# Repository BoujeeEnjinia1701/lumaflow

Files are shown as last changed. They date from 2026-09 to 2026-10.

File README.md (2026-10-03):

# LumaFlow

     

**Area:** Water Security · **TRL:** 3 of 9 (proof of concept on paper) · **Value-engineering target:** $340 USD · **Difficulty:** 2 of 5

Inline UV-C LED reactor with a flow-activated switch and a dose monitor, sized for a household tap.

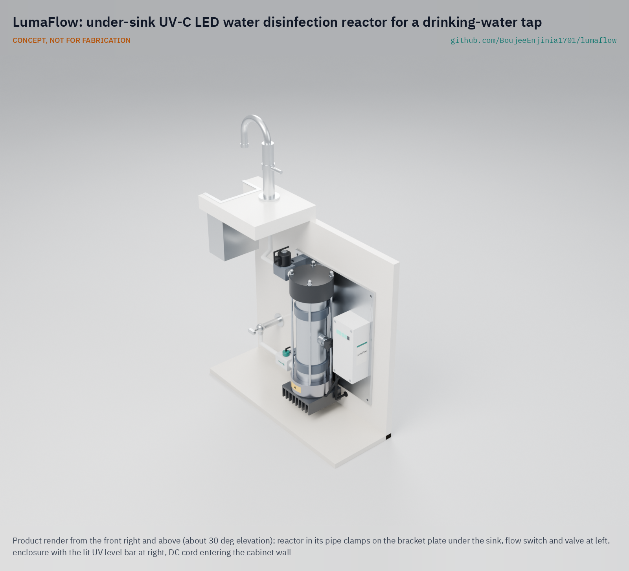
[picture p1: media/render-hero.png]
LumaFlow: under-sink UV-C LED water disinfection reactor for a drinking-water tap, product render


[Exploded render](media/render-exploded.png) · [Detail render](media/render-detail.png) · [Interactive 3D model](media/viewer.html) · [Concept blueprint (PDF)](media/concept-blueprint.pdf) · [General arrangement (PDF)](cad/drawings/LMF-DWG-001.pdf) · [Calculations](docs/04-calcs/01-sizing.md) · [Prototype build plan](docs/05-build-plan.md) · [Design decisions](docs/06-design-decisions.md) · [Review note](docs/REVIEW.md)

## Concept rationale

A UV-C LED reactor that runs only while water flows turns the LED's main weakness, low efficiency, into a small cost: at a household's few minutes of use a day, six LEDs use about 3.8 kWh a year, where a mercury lamp left on all day uses 114 to 193 kWh. Shining the LEDs along a wide, reflective tube, rather than wrapping lamps around a sleeve, keeps the part count low and puts every LED behind one flat quartz window that is easy to seal and service. A photodiode in the tube wall and a normally closed valve mean that a weak dose stops the water rather than passing it silently.

The design is open and garage-buildable because the people who most need point-of-use disinfection, households on private wells and small water projects, are the least served by closed commercial units. Every dimension, dose calculation and part is published, so a university lab, a maker space or a water charity can build one from catalog LEDs, a stainless tube, a machined end cap and push-fit plumbing, test it and improve it.

## Burning platform

Unsafe water remains one of the largest preventable causes of illness. In 2022, 2.2 billion people lacked safely managed drinking water, and at least 1.7 billion used a source contaminated with faeces; microbiologically contaminated drinking water is estimated to cause about 505,000 diarrhoeal deaths each year ([WHO drinking-water fact sheet](https://www.who.int/news-room/fact-sheets/detail/drinking-water)).

The gap is not confined to low-income countries. More than 43 million people in the United States, about 15 % of the population, rely on private domestic wells whose water quality is not regulated by the federal Safe Drinking Water Act ([USGS](https://www.usgs.gov/mission-areas/water-resources/science/domestic-private-supply-wells)), and an estimated three to four million Canadians are served by private supplies ([CMAJ, 2010](https://www.cmaj.ca/content/182/10/1061)). Each of those households is its own water utility, usually without monitoring.

## Where it could be used

### By industry

| Industry | Use |
| --- | --- |
| Residential water treatment | Point-of-use disinfection at a kitchen drinking-water tap on a private well or rainwater tank |
| Rural health clinics | A low-maintenance disinfection stage for the tap used for drinking and hand hygiene |
| Schools and community water points | A metered, monitored barrier on an indoor drinking tap, with a visible fault light |
| Humanitarian and development programs | An open reference design that local workshops can build and repair |
| Research and education | A test bed for reactor optics, LED aging and dose sensing |
| Recreational and off-grid buildings | Cabins, boats and camps on untreated supplies, with 24 V DC power |

### By country or region

| Country or region | Why it matters there |
| --- | --- |
| United States | More than 43 million people drink from private wells outside federal drinking-water regulation ([USGS](https://www.usgs.gov/mission-areas/water-resources/science/domestic-private-supply-wells)) |
| Canada | Three to four million people, about one in eight, are served by private supplies ([CMAJ](https://www.cmaj.ca/content/182/10/1061)) |
| Sub-Saharan Africa | The gap between urban and rural coverage of safely managed drinking water, 38 percentage points in 2022, is the widest of any region ([WHO and UNICEF JMP, 2023, p. 14](https://cdn.who.int/media/docs/default-source/wash-documents/jmp-2023_layout_v3launch_5july_low-reswhowebsite.pdf)); rural households and clinics are the users a small, flow-switched unit serves |
| Bangladesh | In the national Multiple Indicator Cluster Survey of 2019, children in households whose drinking water carried high *E. coli* contamination were 2.28 times as likely to have diarrhea as those in low-risk households ([Khan et al., 2022](https://link.springer.com/article/10.1007/s11356-021-18460-9)) |
| Latin America and the Caribbean | The gap between urban and rural coverage of safely managed drinking water, 27 percentage points in 2022, is second only to sub-Saharan Africa ([WHO and UNICEF JMP, 2023, p. 14](https://cdn.who.int/media/docs/default-source/wash-documents/jmp-2023_layout_v3launch_5july_low-reswhowebsite.pdf)) |
| Pacific islands (Oceania) | At least basic drinking water reached 93 % of urban but only 51 % of rural people in 2022 ([WHO and UNICEF JMP, 2023, p. 14](https://cdn.who.int/media/docs/default-source/wash-documents/jmp-2023_layout_v3launch_5july_low-reswhowebsite.pdf)); a unit that runs on 24 V DC suits off-grid homes |

## What sparked the idea

The idea traces back to one of the first patents on ultraviolet water sterilization, filed on 7 June 1910 by Victor Henri, André Helbronner and Max von Recklinghausen ([US 1,151,267](https://patents.google.com/patent/US1151267)). Their apparatus kept a quartz mercury-vapor lamp outside the water, ran the liquid past it and lined the channel with reflecting metal "so that the rays which pass through the liquid are caused to re-traverse the same." LumaFlow keeps that arrangement, a light source behind a quartz window and a reflective channel, and swaps the mercury lamp for UV-C LEDs that switch on only when water flows.

## Problem

Point-of-use disinfection often depends on mercury UV lamps that break.

## Concept

Water flows up a stainless tube lined with high-reflectance PTFE (50 mm bore, 242 mm water column) while six 275 nm UV-C LEDs at the bottom shine up through a quartz window. A flow sensor switches the LEDs on only while water runs, and a UV-C photodiode in the tube wall estimates the dose; if it falls too low, a normally closed valve shuts off the water and an alarm sounds. A five-segment bar on the enclosure shows the UV level relative to the alarm threshold. The TRL 3 calculations ([LMF-CAL-001](docs/04-calcs/01-sizing.md)) give a dose of 51 to 75 mJ/cm² at the 1.2 L/min (0.32 gpm) design flow in clear water (90 %/cm UV transmittance), above the 40 mJ/cm² target, and 17 to 21 mJ/cm² in the 70 %/cm test water, which stays below it. The unit draws 22.6 W while flowing and 0.21 W on standby. Value-engineering target: USD 340. Estimated cost of the constructable design: USD 416 (USD 76 over the target; see the [design decisions register](docs/06-design-decisions.md)).

Full design precis: [docs/02-concept.md](docs/02-concept.md)

## Key components

- Six 275 nm UV-C LEDs on a heat sink with a board temperature sensor, cooled through a 316 stainless lower end cap into the water
- 316 stainless reactor tube with a high-reflectance PTFE liner (50 mm bore) and top disc; acetal upper cap shielded from UV-C
- Fused quartz window (57 x 10 mm) between the LEDs and the water
- Hall-effect flow sensor (15 Hz per L/min) acting as the flow switch
- UV-C photodiode dose monitor in the tube wall at mid height
- Controller with constant-current LED driver, normally closed shutoff valve, external 24 V adapter
- At installation: a sediment pre-filter and a pressure-limiting valve at 4 bar (58 psi) or less

The priced bill of materials is in [bom/bom.csv](bom/bom.csv); the parametric model is `cad/src/model.py`, with STEP and STL exports in `cad/step/` and `cad/stl/`.

## Building the prototype

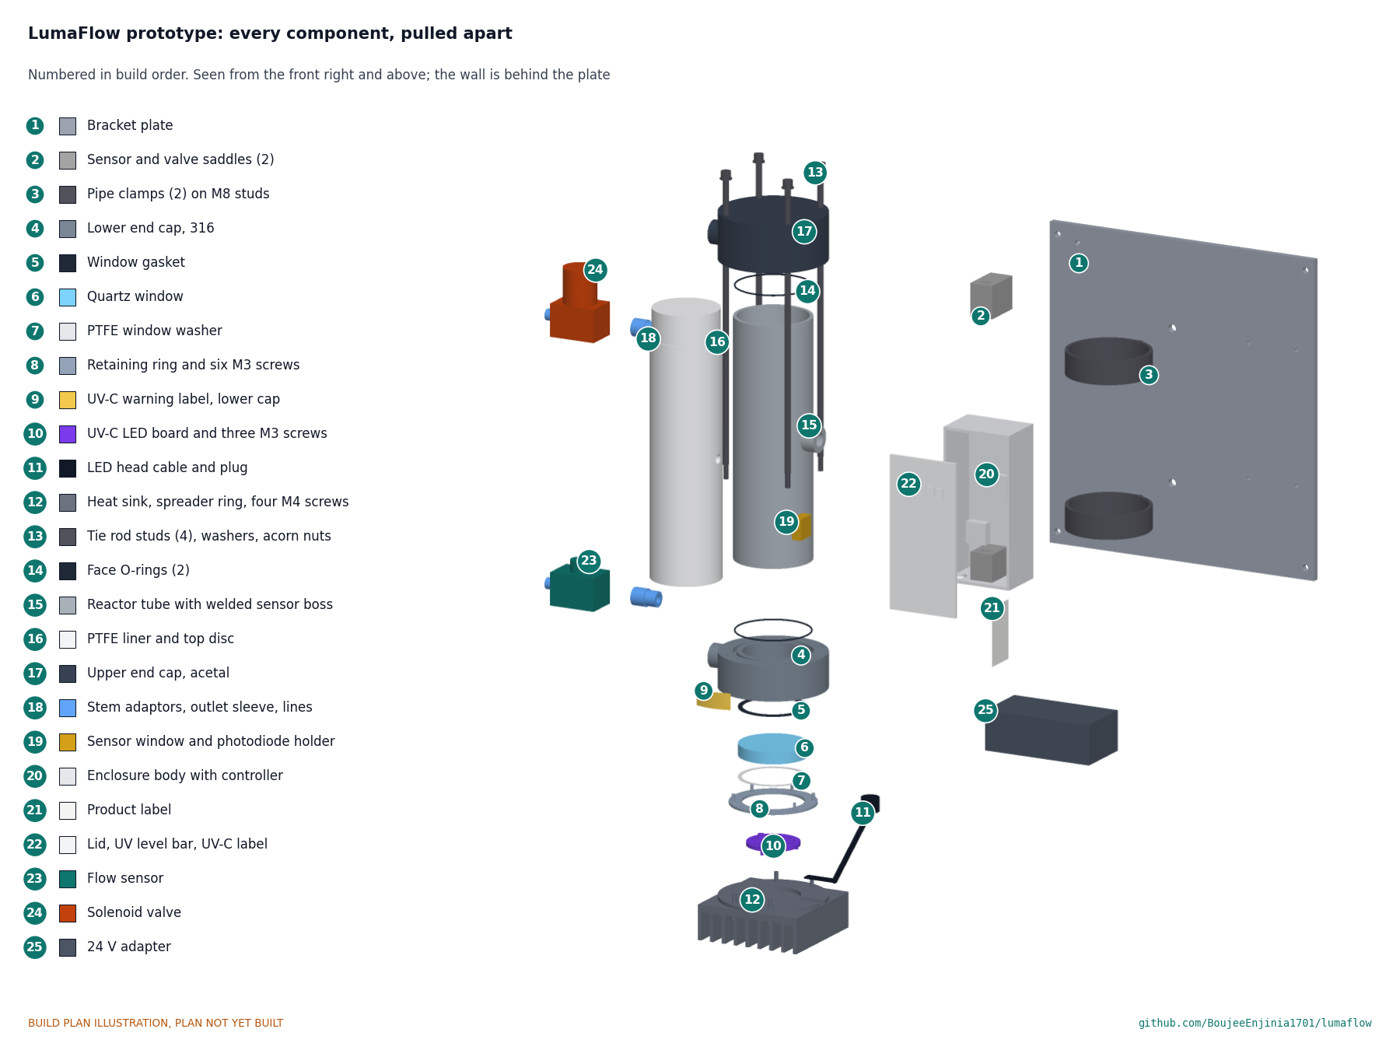
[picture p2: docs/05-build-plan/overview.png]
LumaFlow prototype: every component pulled apart and numbered in build order


The [prototype build plan](docs/05-build-plan.md) (LMF-BLD-001) shows, in pictures, how to make each of the 25 components and put them together in sixteen steps; nothing has been built yet. The made parts are a drilled aluminium bracket plate with printed saddles, a machined stainless lower end cap, a stainless window retaining ring, a drilled heat sink and spreader ring, tie rod studs, the stainless tube with a welded sensor boss, the PTFE liner, a machined acetal upper end cap, a photodiode holder and a printed enclosure; the rest is bought. Writing the plan made the design buildable: the window now goes in from below and is clamped on a PTFE washer by a ring, the tube ends seal on O-rings, the tie rods are studs in the lower cap, the upper cap's roof is thicker, the ports are threaded and the bracket holds the reactor in two pipe clamps (LMF-DDR-003, accepted by Amish on 2026-10-02). The LED head plugs in under the enclosure through an interlock loop on a cable too short for the head to come off while plugged in, and the lid carries a five-segment UV level bar. Every picture is drawn from the model, and the model checks that each part touches what it should and clears what it should not.

## Safety

> UV-C light damages eyes and skin. Interlock the housing and the LED head so LEDs cannot run when either is open, and keep the UV-C warning labels in place. LumaFlow is a research and educational prototype, not a certified water treatment device, and its dose is calculated, not measured; do not rely on it as a barrier for drinking water. See the safety section of the [design precis](docs/02-concept.md).

## Repository layout

| Folder | Contents |
| --- | --- |
| `docs/` | Problem, concept, requirements, calculations and design decisions |
| `cad/src/` | build123d Python source, the source of truth for all geometry |
| `cad/step/`, `cad/stl/` | Exported models for FreeCAD, other CAD tools and printing |
| `cad/drawings/` | 2D sketches and dimensioned drawings |
| `bom/` | Bill of materials |
| `electronics/` | KiCad schematics and PCB layouts |
| `firmware/` | Microcontroller code |
| `media/` | Renders, perspectives and photos |
| `build-log/` | Dated prototyping notes |

## Documentation

Controlled documents follow the portfolio [documentation standard](.kit/STANDARDS.md). Each carries a document ID (LMF-PRC-001 for the precis), a version and a revision history. Branded PDFs are built with `python .kit/render.py` and attached to GitHub Releases when a document is tagged, for example `LMF-PRC-001/v1.0`.

## Credits

Designed by Amish Chadha. See [CONTRIBUTORS.md](CONTRIBUTORS.md) for roles. To cite this design, use [CITATION.cff](CITATION.cff) (GitHub shows it as "Cite this repository").

AI assistance (Claude) was used to accelerate concept renders, prototype documentation and first-pass sizing calculations. Design direction and all decisions are Amish Chadha's, recorded in this repository's decision records (`docs/decisions/`).

## Licenses

- **Hardware** (CAD, drawings, BOM, electronics): [CERN-OHL-S v2](LICENSE)
- **Software** (firmware, scripts, notebooks): [MIT](LICENSE-SOFTWARE)

A project of the [Design Molecule](https://designmolecule.com) lab.

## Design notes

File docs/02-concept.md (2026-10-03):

---
doc_id: LMF-PRC-001
title: LumaFlow design precis
project: LumaFlow
doc_type: Design precis
version: "0.8"
status: Draft
date: '2026-10-02'
author: Amish Chadha
license: CERN-OHL-S-2.0
revisions:
- version: "0.1"
  date: '2026-09-24'
  author: Amish Chadha
  change: Initial scaffold
- version: "0.2"
  date: '2026-09-25'
  author: Amish Chadha
  change: Populate to TRL 2 (architecture, components, dose, power, thermal and window estimates, safety, media)
- version: "0.3"
  date: '2026-09-25'
  author: Amish Chadha
  change: Record Amish's decisions (LMF-DDR-001); TRL 3 design (316 lower cap, PTFE-shielded acetal upper cap, tie rods); numbers replaced by LMF-CAL-001, including the dose shortfall
- version: "0.4"
  date: '2026-09-25'
  author: Amish Chadha
  change: Recommendations accepted by Amish (DDR-002); 50 mm bore with high-reflectance PTFE liner at 1.2 L/min, wall dose sensor, 15 Hz per L/min flow sensor, pressure limiter, thermal cut-back; numbers from LMF-CAL-001 v0.2
- version: "0.5"
  date: '2026-09-26'
  author: Amish Chadha
  change: Budget top-up approved by Amish ($340); R16 met
- version: "0.6"
  date: '2026-10-01'
  author: Amish Chadha
  change: "Design made constructable (LMF-DDR-003): components 13 to 18 updated; cost reported against the value-engineering target"
- version: "0.7"
  date: '2026-10-02'
  author: Amish Chadha
  change: "UV level bar, labels, idle pulse and partner as decided on 2026-10-02 (LMF-DEC-001)"
- version: "0.8"
  date: '2026-10-02'
  author: Amish Chadha
  change: "Approved follow-ups carried out (LMF-CAL-001 v0.6): window on a 0.5 mm PTFE washer, LED head interlock plug, UV level bar in place of the status light, labels; figures updated"
---

# LumaFlow design precis

## Summary

LumaFlow is an inline UV-C LED reactor with a flow-activated switch and a dose monitor, sized for a household tap. Water flows up a stainless tube lined with high-reflectance PTFE, with a 50 mm bore, while six 275 nm LEDs at the bottom shine up a 242 mm water column through a quartz window. A Hall-effect flow sensor turns the LEDs on only while water runs, and a UV-C photodiode in the tube wall at mid height measures the light in the water, which lets the controller estimate the dose and close a valve if it falls too low.

The first TRL 3 calculation (LMF-CAL-001 v0.1) showed that the original 25 mm bore lost half of the light to the wall and delivered only 14.7 to 19.0 mJ/cm² at 2 L/min. Amish accepted the recommended route on 2026-09-25 (LMF-DDR-002): a wider bore, a higher-reflectance liner and a modest flow cut. With a 50 mm bore, a liner reflectance of 0.95 and a design flow of 1.2 L/min (0.32 gpm), the reduction equivalent dose (RED) in clear water (90 %/cm UV transmittance) is 50.9 to 74.9 mJ/cm², so **R2 is met**. At the 70 %/cm test condition it is 17.0 to 21.3 mJ/cm² (**R3 not met**, accepted by decision D1). The unit draws 22.6 W while water flows and 0.21 W on standby. Value-engineering target: USD 340. Estimated cost of the constructable design: USD 416 (USD 76 over the target). The design was made physically buildable on 2026-10-01 (LMF-DDR-003, accepted by Amish on 2026-10-02 with the window seat changed to a PTFE washer), and the prototype build plan LMF-BLD-001 shows how to make and fit every part.

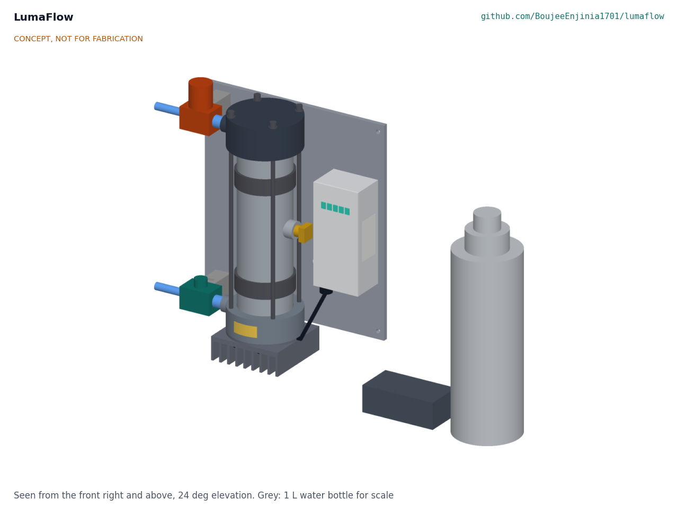
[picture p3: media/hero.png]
Hero render


*Figure 1. LumaFlow model, mounted on its wall bracket under a sink, with the 24 V adapter on the cabinet floor. The grey 1 L bottle is for scale.*

## How it works

1. **Flow starts.** When someone opens the drinking-water faucet, water enters through the Hall-effect flow sensor (item 8). Its pulses, 15 per second for each L/min, tell the controller that flow has started and how fast it is.
2. **LEDs on.** The controller opens the normally closed outlet valve (item 11) and drives the six 275 nm LEDs (item 4) at 350 mA. At the 0.3 L/min threshold the first sensor pulse arrives within 0.22 s, so switch-on takes up to 0.24 s against the 0.5 s target (LMF-CAL-001, D2). LEDs reach full output almost at once, so no warm-up or bypass is needed.
3. **Irradiate.** The LEDs sit 1.3 mm under a 10 mm fused quartz window (item 3), which rests on a 0.5 mm PTFE washer on its stainless retaining ring, in the 316 stainless lower end cap (item 6). Water enters the lower cap just above the window, flows up the 50 mm bore of the PTFE liner (item 2) at about 1 cm/s and leaves through a 316 insert in the acetal upper cap (item 7) after about 22 s. The wide bore lets light cross more water between wall reflections, and the liner returns about 95 % of the light that reaches it, so the water absorbs 53 % of the LED output at 90 %/cm.
4. **Measure.** A UV-C photodiode (item 9) behind an 8 mm quartz window in the tube wall at mid height sees the light in the water. Its signal falls if the water's UVT drops, the liner or window fouls or the LEDs age. The controller combines that reading with the flow rate to estimate the dose, using a proportional rule that blames every loss of signal on the LEDs, which always under-reads (LMF-CAL-001, C3 to C5).
5. **Alarm and shut off.** If the estimated dose falls below 40 mJ/cm², the flow exceeds its limit, a sensor fails or the enclosure lid is opened, the controller closes the valve, sounds the buzzer and shows the fault on the UV level bar. In normal running the five-segment bar shows the UV level relative to the alarm threshold, read from the wall sensor (R18); it is not a dose reading. With fresh LEDs this happens below about 89 %/cm UVT. The valve also closes if power is lost, so no untreated water passes silently.
6. **Stay cool.** A temperature sensor on the LED board lets the controller cut LED current above 50 °C. A cut-back lowers the dose, which the photodiode sees, so the alarm rule still protects the user.
7. **Flow stops.** The LEDs stay on for 5 s after flow stops, then everything switches off.

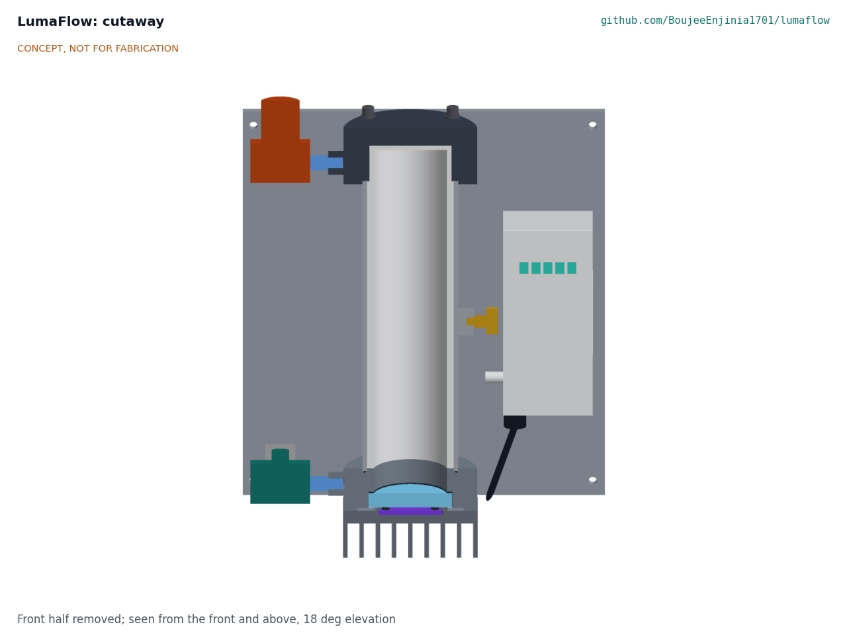
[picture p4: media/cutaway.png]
Cutaway


*Figure 2. Cutaway through the reactor axis, looking at the wall. From the bottom: heat sink, LED board, quartz window in the stainless lower cap with the inlet, the 50 mm PTFE-lined tube with the wall photodiode on the right, and the PTFE top disc in the acetal upper cap with the outlet insert. The controller board is in the enclosure on the right.*

## Main components

Numbers match the exploded view (Figure 3), `bom/bom.csv` and drawing LMF-DWG-001 Rev P4.

Table 1. Main components.

| # | Component | Choice | Notes |
| --- | --- | --- | --- |
| 1 | Reactor tube | 316 stainless, 65 mm OD x 3 mm wall x 200 mm, one hole for the sensor window | Carries pressure and blocks all UV-C |
| 2 | High-reflectance PTFE liner and top disc | Sintered or expanded PTFE tube, 50 mm bore, 224 mm long, and a solid 3 mm top disc | Water channel and diffuse reflector (0.95 assumed); shields the acetal cap |
| 3 | Quartz window | UV-grade fused silica, 57 mm diameter x 10 mm, on a 51 mm seat | 6.18 MPa at 8 bar (LMF-CAL-001, G4) |
| 4 | UV-C LED array | Six 275 nm LEDs on a 32 mm circle, about 60 mW each at 350 mA, on one 44 mm aluminum-core board with an NTC temperature sensor | Decision D4; NTC for the thermal cut-back |
| 5 | Heat sink and spreader ring | Finned aluminum sink 90 x 90 x 30 mm and a 90 mm spreader ring to the stainless cap | Water carries 9.0 of 12.7 W of heat |
| 6 | Lower end cap | 316 stainless, 90 mm diameter x 30 mm, LED aperture, window seat, 3/8 in inlet | Stainless because its bore sees full UV-C and it is the water-cooled heat path (confirmed, LMF-DDR-002) |
| 7 | Upper end cap | Acetal, 90 mm diameter x 30 mm, liner pocket, outlet boss | Sees no UV-C behind the PTFE and the 316 insert |
| 8 | Hall-effect flow sensor | Food-grade, 0.3 to 6 L/min, 15 Hz per L/min or more | Switch and meter (decision D5) |
| 9 | UV-C wall photodiode and amplifier | SiC photodiode with transimpedance amplifier behind an 8 mm quartz window in the tube wall, on a clamp-on saddle | Dose monitor at mid height (LMF-DDR-002) |
| 10 | Controller and LED driver | Microcontroller, 350 mA constant-current driver with dimming, valve driver, NTC input, input fuse | Module-based; no custom PCB |
| 11 | Solenoid shutoff valve | 24 V DC, normally closed, food-grade | Closes on alarm or power loss (decision D6) |
| 12 | 24 V power adapter | Certified external adapter, 30 W | The only part at mains voltage (decision D8) |
| 13 | Electronics enclosure | Printed PETG body and lid, lid interlock, five-segment UV level bar on the lid (R18), buzzer, socket for the LED head plug, back screwed to the bracket plate | Dry side only. The LED head plug carries an interlock loop (R12); UV-C warning labels sit inside the lid and on the lower cap, and the product label on the enclosure side (item 19) |
| 14 | Wall bracket | 6 mm aluminium plate with two printed saddles for the flow sensor and valve | Holds the reactor vertical (decision D7) |
| 15 | Fittings, stem adaptors and outlet sleeve | 3/8 in push-fit, stainless stem adaptors in 1/4 BSPP ports, tee to the cold line, 1.2 L/min restrictor, 316 outlet sleeve | Restrictor enforces R1 |
| 16 | Tie rods and hardware | Four M5 316 studs on an 80 mm circle, threaded into the lower cap | 664 N each at 8 bar (G7) |
| 17 | Window retaining ring and seals | 316 ring under the window, EPDM window gasket, two EPDM face O-rings at the tube ends | Added by LMF-DDR-003 |
| 18 | Pipe clamps | Two rubber-lined 65 mm clamps on M8 studs | Added by LMF-DDR-003 |

Not in the BOM, but required at installation: a 5 µm sediment pre-filter and a pressure-limiting valve set at 4 bar (58 psi) or less (R17).

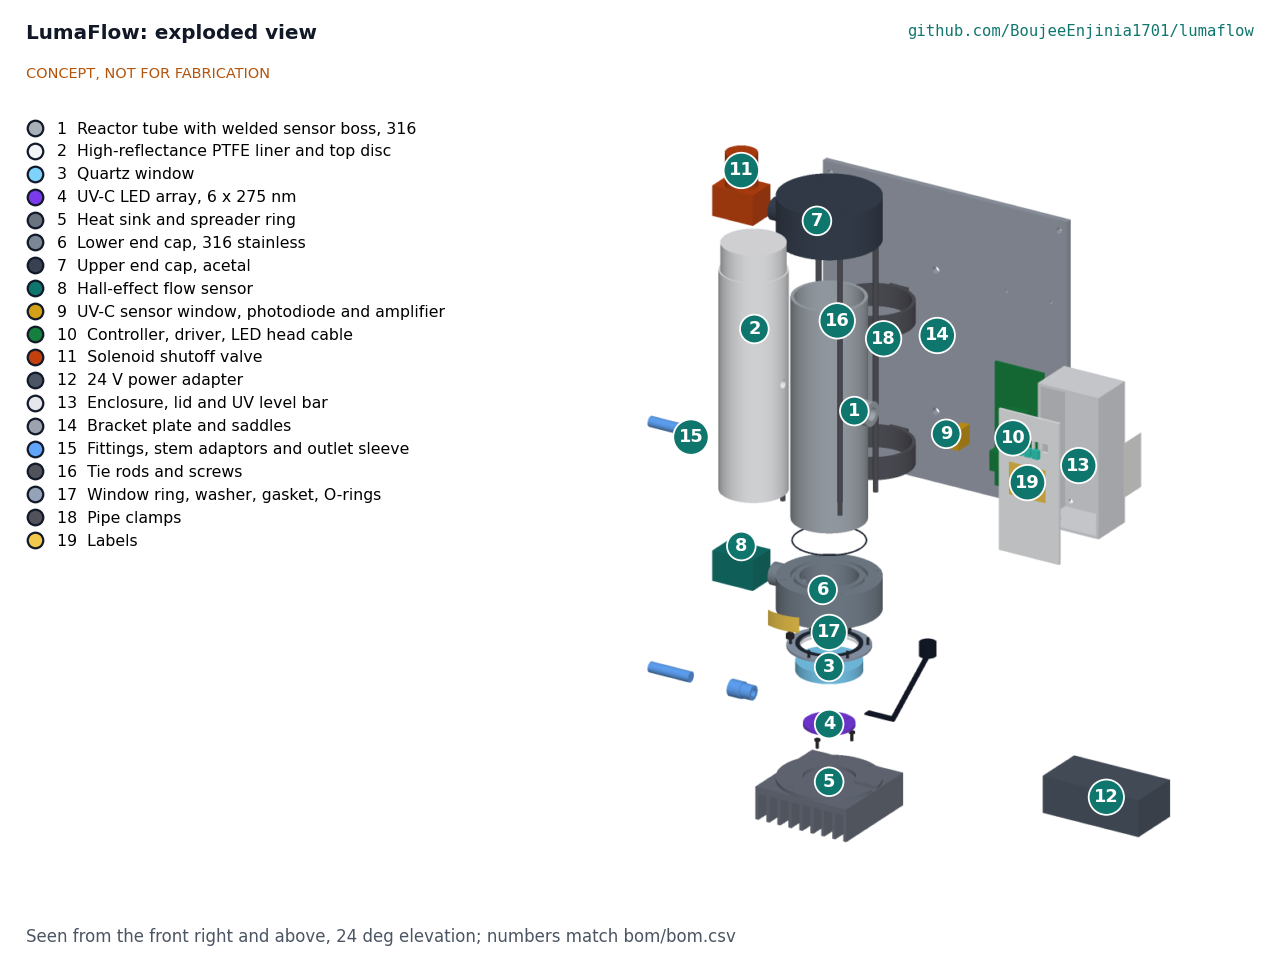
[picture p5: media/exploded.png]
Exploded view


*Figure 3. Exploded view with numbered callouts matching the BOM.*

## Key numbers

Every number in this section comes from LMF-CAL-001 v0.6, which states the assumptions; the tag in brackets is the line of `docs/04-calcs/sizing.py` that prints it.

### Flow

The channel is 50 mm across and 242 mm long and holds 474 mL [A1, A2]. At 1.2 L/min the mean velocity is 1.02 cm/s, the residence time between the ports 22.2 s and the Reynolds number 507, so the flow is laminar [A3, A4]. The entrance length is far longer than the tube [A5], so the true profile lies between plug flow and a parabola; the dose is given for both.

### UV-C dose

Table 2. Dose at 1.2 L/min [B3 to B6].

| Quantity | 90 %/cm UVT (design water) | 70 %/cm UVT (NSF/ANSI 55 test water) |
| --- | --- | --- |
| UV-C entering the water | 84.8 % of 0.36 W | 84.8 % of 0.36 W |
| UV-C absorbed by the water | 52.9 % | 66.5 % |
| Lost at the walls | 25.9 % | 16.4 % |
| Average dose | 75.4 mJ/cm² | 21.5 mJ/cm² |
| **RED (laminar to plug flow)** | **50.9 to 74.9 mJ/cm²** | **17.0 to 21.3 mJ/cm²** |
| Requirement | **R2 met** | **R3 not met** (accepted by D1) |

The liner reflectance is the main optical uncertainty: plain PTFE (0.80) would give 45.2 mJ/cm² and 0.90 gives 48.7 [B8]. LEDs 20 % below rating give 40.7 mJ/cm² [B9]. Six LEDs in this reactor reach 40 mJ/cm² up to 1.56 L/min, and 40 mJ/cm² with a 20 % margin up to 1.26 L/min [J1].

The dose target is the NSF/ANSI 55 Class A dose level for context only ([Fresh Water Systems](https://www.freshwatersystems.com/blogs/blog/nsf-class-a-and-class-b)). 40 mJ/cm² inactivates common bacteria and *Cryptosporidium* by several logs, but adenovirus needs about 186 mJ/cm² for 4 logs ([EPA UV toolkit](https://www.epa.gov/system/files/documents/2022-05/uv-toolkit-815-B-21-007_0.pdf)), so LumaFlow would not be a full virus barrier even at its target. Published flow-through LED reactors show that the reactor layout changes the delivered dose a great deal ([flow-through reactor efficiency](https://www.sciencedirect.com/science/article/abs/pii/S2214714420306966); [cylindrical reactor optimization](https://www.sciencedirect.com/science/article/abs/pii/S2213343724004962)).

### Dose monitor

The wall photodiode gives about 13.4 nA at 90 %/cm, 2.4 nA at 80 %/cm and 0.19 nA at 70 %/cm [C1], and its signal falls 2.6 times as fast as the dose [C2]. With the proportional mapping the alarm threshold is S/S_ref = 0.79 [C3]: it trips below about 89 %/cm with fresh LEDs, or when the LEDs have aged to 79 % of output in 90 %/cm water [C4]. R4 is at risk until the mapping and the 1 s fail-safe are shown in firmware and test. The five-segment UV level bar shows three segments in 90 %/cm water with fresh LEDs and loses its last segment where the alarm trips, so R18 is met [C6].

### Power and energy

Table 3. Power and energy [E1 to E6].

| Quantity | Value | Requirement |
| --- | --- | --- |
| LED electrical power | 13.02 W | |
| Power from mains while flowing | 22.6 W | R9 met (25 W) |
| Standby power | 0.21 W | R9 met (0.5 W) |
| LED on-time | 14.2 min/day, 86 h/year flowing; 92 h/year with the idle pulse of about 10 s every 4 h | 10,000 h in 108 years |
| Energy | 10.4 Wh/day flowing, 0.28 Wh/day for the idle pulse; 3.9 kWh/year | |
| Tap-scale mercury unit of 13 to 22 W running all day ([VIQUA spec sheet](https://viqua.com/wp-content/uploads/LIT520326_SpecSheet.pdf)) | 114 to 193 kWh/year | For comparison |

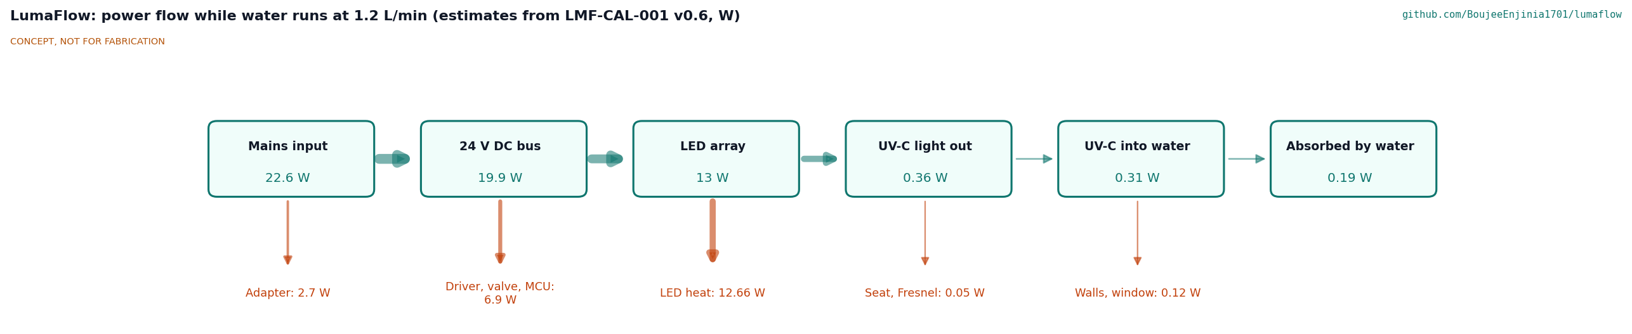
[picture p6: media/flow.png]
Power flow


*Figure 4. Power flow while water runs at 1.2 L/min. All values are estimates from LMF-CAL-001, in watts.*

### Heat

The LEDs turn 12.66 W into heat. The spreader ring passes it into the stainless lower cap, whose wetted bore gives it to the water (8.9 W; the water warms by 0.11 K), and the finned sink gives the rest to the air [F1, F2]. With continuous flow the LED board settles at 37.3 to 45.1 °C over the range of water-film coefficients, 40.5 °C nominal, so R10 is met [F3]. The board sensor cuts LED current above 50 °C as a backstop. With the LEDs stuck on and no flow the board heads for 53 °C [F6], where the cut-back acts; the controller must also switch the LEDs off when flow stops. A 10 s idle pulse warms the still head by 0.16 K [F7].

### Pressure and structure

The unit drops 0.15 bar at 1.2 L/min, not counting the restrictor, against 0.5 bar (R8 met, on assumed flow coefficients) [G2]. The 10 mm window carries 6.18 MPa at 8 bar against a design stress of 6.8 MPa (1,000 psi) for fused quartz ([Momentive](https://www.momentivetech.com/materials/fused-quartz-materials/quartz-properties/mechanical-properties)); R7 is met [G4]. An unprotected 16 bar spike would give 12.4 MPa, so the installation needs a pressure-limiting valve at 4 bar or less (R17), which keeps a transient of twice the setting at 6.18 MPa [G5]. Four M5 rods carry the 2,655 N end load [G7]. The window sits on a 0.5 mm PTFE washer whose 51 mm bore matches the retaining ring, so the open span and the stress are unchanged.

### Size and cost

The unit is 277 x 100 x 322 mm without the adapter, inside R14 [H1], and weighs about 5.0 kg dry and 5.4 kg full of water [H2]. Value-engineering target: USD 340. Estimated cost of the constructable design: USD 416 (USD 76 over the target) [I1]; the LEDs ($54), the stainless lower cap ($48) and the high-reflectance liner ($45) are the largest lines.

## Key design choices

Items marked "Decided" were decided by Amish on 2026-09-25, going with the recommendation (LMF-DDR-001, D1 to D9, and LMF-DDR-002, E1 to E8).

- **Axial LED head with a flat window (Decided, D3).** LEDs at one end shine along the tube through a flat window; this uses few LEDs and a simple reflector.
- **Wide bore, high-reflectance liner and 1.2 L/min (Decided, LMF-DDR-002).** A 50 mm bore with a liner of reflectance 0.95 and a modest flow cut close the dose gap found in LMF-CAL-001 v0.1. Lowering the flow alone (to about 0.6 L/min in the old reactor) is the fallback.
- **Wall dose sensor (Decided, LMF-DDR-002).** The photodiode moved from the top disc to the tube wall at mid height, with the proportional mapping kept. A second reference sensor near the LEDs, to separate LED aging from water quality, remains an optional idea.
- **275 nm LEDs (Decided, D4).** 275 nm gives the most UV-C output per dollar ([Tech-LED](https://tech-led.com/uv-c-leds-for-disinfection-and-sterilization-component-selection-265-280-nm/)); prices to be revisited. The dose calculation takes the organism's response at 275 nm as equal to that at 254 nm, which must be checked.
- **Design water quality and dose target (Decided, D1).** Design for 90 %/cm UVT, alarm and close the valve below 40 mJ/cm², and keep R3 visibly not met; flow limiting in poor water (Option C) is a later upgrade.
- **Flow sensor as the switch (Decided, D5), at 15 Hz per L/min or more (Decided, LMF-DDR-002).**
- **Normally closed outlet valve (Decided, D6).** Fails closed on alarm and on power loss.
- **Vertical mounting, flow upward (Decided, D7).** Purges air bubbles from under the window.
- **External 24 V adapter (Decided, D8).** Certified adapter on a GFCI or RCD-protected outlet.
- **End caps (Decided, LMF-DDR-002).** 316 stainless lower cap for UV-C exposure and heat, acetal upper cap shielded by the PTFE liner, top disc and a 316 outlet insert.
- **Pressure limiter and thermal cut-back (Decided, LMF-DDR-002).** A pressure-limiting valve upstream is an installation requirement (R17); a board temperature sensor cuts LED current above 50 °C (R10).
- **Budget (Decided, D2, and LMF-DDR-002).** `budget_usd` was $225. The recommendation to hold the budget until the dose route was chosen and then re-price has been carried out: the re-priced BOM is $338.00. Budget top-up to $340: decided by Amish, 2026-09-26 (LMF-DDR-002, O4); `budget_usd` is now $340.

## Safety

> **Safety:** LumaFlow emits UV-C light that injures eyes and skin, sits under pressure next to mains power in a wet cabinet, and is meant to make water safe to drink. Its dose is calculated, not measured. It is a research and educational prototype, not a certified water treatment device. Do not rely on it as a barrier for drinking water.

- **UV-C exposure.** UV-C burns the cornea and skin within seconds to minutes at close range and is invisible. The stainless tube, stainless lower cap, sealed sensor boss and PTFE-shielded upper cap block all UV-C in normal use. An interlock on the enclosure lid (a reed switch) and on the LED head (a loop in the head's plug, on a cable too short for the head to come off while plugged in) cuts LED power when either is opened, and no one should look into the bore, window or sensor port while the LEDs can run. Any bench work needs UV-C blocking eyewear and covered skin.
- **False sense of safety.** The calculated dose of 50.9 to 74.9 mJ/cm² at 90 %/cm rests on an assumed liner reflectance and organism response and has not been measured. In poorer water the dose falls quickly (17.0 mJ/cm² at 70 %/cm). UV does not remove chemicals, lead, nitrate or particles, leaves no residual disinfectant, and works poorly in cloudy or iron-rich water. A dose below target must stop the water, not only warn. Downstream pipework and the faucet can grow biofilm.
- **Pressure and leaks.** Supply pressure acts on the window, caps, sensor window and tubing; the larger window has a 9 % margin at 8 bar, and an unprotected spike would overstress it. Fit a shutoff valve and a pressure-limiting valve at 4 bar or less upstream. A cracked window would flood the LED head; the board runs at 24 V, so the hazard is short circuit and loss of treatment rather than shock. The fuse on the 24 V input and a leak check in the fault logic are required.
- **Electrical.** Mains is confined to the certified adapter, which should plug into a GFCI or RCD-protected outlet above any likely water level in the cabinet.
- **Heat.** The board temperature sensor cuts LED current above 50 °C, and the controller must switch the LEDs off when flow stops.
- **Materials.** UV-C degrades most plastics; only PTFE, quartz and metal may see it. Every wetted part must be food-contact grade.

## Open questions

- [x] Design water quality and dose target (decided, D1).
- [x] Estimate the reactor efficiency for this axial, laminar geometry (LMF-CAL-001: 0.67 laminar in the 50 mm bore).
- [x] Choose a route to close R2 (decided, LMF-DDR-002: 50 mm bore, 0.95 liner, 1.2 L/min).
- [x] Move the dose sensor to the tube wall (decided, LMF-DDR-002).
- [x] Confirm the end cap materials (decided, LMF-DDR-002).
- [x] Set the budget figure for the $338.00 BOM: $340, decided by Amish, 2026-09-26.
- [ ] Measure the wetted reflectance of the liner at 275 nm, and the organism response at 275 nm (TRL 4, on hold).
- [ ] Confirm the flow coefficients of the sensor and valve (R8) and the water-film coefficient in the lower cap (R10).
- [x] Idle LED pulse: a firmware rule runs the LEDs for about 10 s every 4 h of idle, with both interlocks and the valve logic unchanged; plate counts at TRL 4 check its effect. Decided by Amish, 2026-10-02 (LMF-DEC-001).
- [ ] Partner with real well-water UVT data: a university extension programme for private well owners, with the Texas A&M AgriLife Extension Texas Well Owner Network as the first candidate to approach. Decided by Amish, 2026-10-02 (LMF-DEC-001).

Concept media: [blueprint sheet](../media/concept-blueprint.pdf), [interactive 3D model](../media/viewer.html). General arrangement: [LMF-DWG-001](../cad/drawings/LMF-DWG-001.pdf).

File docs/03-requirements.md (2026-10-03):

---
doc_id: LMF-REQ-001
title: LumaFlow requirements
project: LumaFlow
doc_type: Requirements
version: "0.8"
status: Draft
date: '2026-10-02'
author: Amish Chadha
license: CERN-OHL-S-2.0
revisions:
- version: "0.1"
  date: '2026-09-24'
  author: Amish Chadha
  change: Initial scaffold
- version: "0.2"
  date: '2026-09-25'
  author: Amish Chadha
  change: First measurable requirements for TRL 2, with status against the concept estimates
- version: "0.3"
  date: '2026-09-25'
  author: Amish Chadha
  change: Record Amish's decisions (LMF-DDR-001); R16 redefined to $225; R7 design stress sourced (6.8 MPa); status from LMF-CAL-001
- version: "0.4"
  date: '2026-09-25'
  author: Amish Chadha
  change: Recommendations accepted by Amish (DDR-002); R1 to 1.2 L/min, R8 restated, R10 adds the thermal cut-back, new R17 pressure limiter; status from LMF-CAL-001 v0.2
- version: "0.5"
  date: '2026-09-26'
  author: Amish Chadha
  change: Budget top-up approved by Amish; R16 target $340, now met (LMF-CAL-001 v0.3)
- version: "0.6"
  date: '2026-10-01'
  author: Amish Chadha
  change: Rerun for the constructable design (LMF-DDR-003); R16 reported against the value-engineering target; R15 note
- version: "0.7"
  date: '2026-10-02'
  author: Amish Chadha
  change: "R12 status names the LED head loop wire; R18 added for the five-segment UV level bar (LMF-DEC-001, 2026-10-02)"
- version: "0.8"
  date: '2026-10-02'
  author: Amish Chadha
  change: "Approved follow-ups carried out (LMF-CAL-001 v0.6): R18 now met; R12 interlock now in the model and build plan; R2, R3, R4, R10 and R16 figures updated for the PTFE window washer and the new BOM lines"
---

# LumaFlow requirements

These are the requirements for the concept, checked by calculation at TRL 3 in LMF-CAL-001 v0.6, for the constructable design of LMF-DDR-003 with the decisions of 2026-10-02 (LMF-DEC-001) carried into it. The status column reports that note; bracketed tags such as [B5] point to the line of `docs/04-calcs/sizing.py` that carries the number. One requirement is **not met**: R3 (dose at the 70 %/cm test condition, accepted as not met by decision D1). R16 (cost) is reported against its value-engineering target: the constructable design is estimated at USD 416, USD 76 over the USD 340 target. One is at risk: R4. The dose targets (R2, R3) and the budget (R16) follow Amish's decisions in LMF-DDR-001; R1, R8, R10 and the new R17 follow the recommendations Amish accepted on 2026-09-25 (LMF-DDR-002).

Table 1. Requirements and status at TRL 3.

| ID | Requirement | Target | Status (LMF-CAL-001 v0.6) | Verification |
| --- | --- | --- | --- | --- |
| R1 | Deliver a useful drinking-water flow | 1.2 L/min (0.32 gpm) at the faucet, capped by a flow restrictor (was 2.0 L/min; reduced by LMF-DDR-002 so that R2 is met with margin) | Met by design [A3] | Restrictor rating; flow calculation |
| R2 | Deliver the Class A dose level in clear water | Reduction equivalent dose (RED) of 40 mJ/cm² or more at 1.2 L/min and UV transmittance (UVT) of 90 %/cm | Met (50.9 laminar to 74.9 plug mJ/cm², with the window on its 0.5 mm PTFE washer) [B5] | Ray-trace dose calculation; later biodosimetry |
| R3 | Deliver the Class A dose level at the NSF/ANSI 55 test water quality | RED of 40 mJ/cm² or more at 1.2 L/min and 70 %/cm UVT | **Not met** (17.0 to 21.3 mJ/cm²) [B6]; kept visibly not met by decision D1 | Dose calculation |
| R4 | Monitor the dose and fail safe | UV-C sensor in the tube wall reading through the water; visual and audible alarm and outlet valve closed within 1 s when the estimated dose falls below 40 mJ/cm², the sensor fails or power is lost | At risk: the wall signal is 13.4 nA at 90 %/cm and 0.19 nA at 70 %/cm, and the proportional mapping trips below about 89 %/cm, but the mapping and 1 s fail-safe need firmware and a test [C1, C4] | Signal calculation; later firmware and test |
| R5 | Switch with the flow | LEDs on within 0.5 s of flow above 0.3 L/min; LEDs held on for 5 s after flow stops; LEDs off otherwise | Met (0.24 s worst case with a 15 Hz per L/min sensor) [D2] | Timing calculation; later firmware sketch review |
| R6 | No mercury and no warm-up | No mercury in any part; full UV output within 0.1 s of switch-on | Met by design | Design review; LED datasheet |
| R7 | Withstand household water pressure | Working pressure 8 bar (116 psi); quartz window stress 6.8 MPa (1,000 psi) or less at 8 bar | Met (6.18 MPa with a 10 mm window on a 51 mm seat) [G4] | Plate stress calculation |
| R8 | Low pressure drop | 0.5 bar (7 psi) or less across the unit at 1.2 L/min, excluding the flow restrictor, which absorbs excess supply pressure by design; sensor and valve flow coefficients from their datasheets | Met (0.15 bar on assumed flow coefficients; datasheet values to be confirmed when parts are chosen) [G2] | Component data and hydraulic calculation |
| R9 | Low energy use | 25 W or less while water flows; 0.5 W or less on standby | Met (22.6 W and 0.21 W) [E1, E2] | Power budget calculation |
| R10 | Keep the LEDs cool | LED board 50 °C or less with 30 °C cabinet air and 25 °C water, including the 5 s run-on; a board temperature sensor cuts LED current above 50 °C | Met (37.3 to 45.1 °C over the film-coefficient range) [F3] | Thermal calculation; cut-back reviewed as a firmware rule |
| R11 | Food-safe wetted parts | Every wetted material food-contact grade (316 stainless steel, PTFE, fused quartz, EPDM or silicone O-rings, acetal); no UV-C on any plastic other than PTFE | Met by design (316 lower cap; PTFE liner, top disc and 316 insert shield the acetal upper cap) | Material review of the model |
| R12 | Contain the UV-C light | No UV-C outside the unit in normal use; LEDs cannot run with the LED head or enclosure lid removed | Met by design: lid reed switch, and an interlock loop in the LED head's plug; the head's 95 mm cable is 39 mm too short for the head to clear the cap while still plugged in (model check; decided 2026-10-02, LMF-DEC-001) | Design review of interlock and light path |
| R13 | Electrical safety | Only 24 V DC at the unit; mains confined to a certified external adapter; fuse on the 24 V input | Met by design | Design review |
| R14 | Fit under a kitchen sink | Envelope 350 x 150 x 350 mm (13.8 x 5.9 x 13.8 in) or less, excluding the adapter | Met (277 x 100 x 322 mm) [H1] | Parametric model |
| R15 | Easy service | Window and LED head replaceable with hand tools in 15 min or less; status LED shows run, fault and service due | Not verifiable at TRL 3 (LED head unplugged, then off on four screws from below, and window out after six ring screws, with no plumbing disturbed; needs a build to time). Run, fault and service due are shown on the UV level bar, which replaced the single status light (2026-10-02) | Timed service on a build |
| R16 | Low cost and buildable | Value-engineering target of USD 340 per unit in parts (`budget_usd`, a hypothetical control target, not a limit; set from $200 by decision D2, then $225, then $340 by the top-up Amish approved on 2026-09-26); no custom PCB for the first build | Over the value-engineering target by USD 76 (estimated cost of the constructable design USD 416; the concept was $338.00) [I1] | Priced BOM |
| R17 | Pressure protection (installation) | A pressure-limiting valve upstream of the unit, set at 4 bar (58 psi) or less, so that transients stay within the 8 bar window rating (new, LMF-DDR-002) | Met (window 3.09 MPa at 4 bar, 6.18 MPa at a transient of twice the setting) [G5] | Plate stress calculation; installation instructions |
| R18 | Show UV level at a glance | A five-segment bar on the enclosure lid showing UV level relative to the alarm threshold, read from the wall sensor; labelled as UV level, not as a dose in units (new, decided by Amish on 2026-10-02, LMF-DEC-001) | Met by design: three of five segments lit at 90 %/cm with rated LEDs, the last segment going out where the alarm trips; in the model and BOM line 13 [C6] | Design review; later bench check against the wall sensor reading |

## Assumptions

- **Water quality.** The design water is clear, pre-filtered well water (decision D9): UVT of 90 %/cm or better at 275 nm, turbidity below 1 NTU, after a 5 µm sediment pre-filter. UVT must be measured for each site. Iron, manganese and hardness foul the window and must be within the limits commonly given for UV systems; this is an installation requirement, not a LumaFlow feature.
- **Dose target.** 40 mJ/cm² is the NSF/ANSI 55 Class A dose level. Reaching it would not make LumaFlow Class A compliant or certified. It inactivates bacteria and protozoa such as *Cryptosporidium* by several logs but gives a much smaller log reduction of adenovirus, which the US EPA dose tables show needs about 186 mJ/cm² for 4 logs ([EPA UV toolkit](https://www.epa.gov/system/files/documents/2022-05/uv-toolkit-815-B-21-007_0.pdf)). RED in LMF-CAL-001 is computed for a challenge organism of 20 mJ/cm² per log.
- **Liner reflectance.** R2 rests on a wetted reflectance of 0.95 for the high-reflectance PTFE liner, which must be measured; plain PTFE (0.80) would give 45.2 mJ/cm², still above 40 (LMF-CAL-001, B8).
- **Pressure.** The pressure-limiting valve (R17) is part of the installation, like the sediment pre-filter, and is not in the LumaFlow BOM.
- **Demand.** 10 to 20 L per household per day, drawn in about 20 short draws.
- R3 is kept as stated so that the gap stays visible. The R16 figure of $340 is a value-engineering target (Amish, 2026-10-01); the cost drivers and savings worth trying are in the design decisions register, LMF-DEC-001.

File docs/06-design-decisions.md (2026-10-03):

---
doc_id: LMF-DEC-001
title: LumaFlow design decisions register
project: LumaFlow
doc_type: Design decisions register
version: "0.3"
status: Draft
date: '2026-10-02'
author: Amish Chadha
license: CERN-OHL-S-2.0
revisions:
- version: "0.1"
  date: '2026-10-01'
  author: Amish Chadha
  change: Register opened with the build plan; budget treated as a value-engineering target
- version: "0.2"
  date: '2026-10-02'
  author: Amish Chadha
  change: "Amish approved the recommendations for open decisions 1 to 10 (LMF-DDR-003 accepted with the window seat changed); moved to decisions made; To confirm item 8 and Value engineering updated"
- version: "0.3"
  date: '2026-10-02'
  author: Amish Chadha
  change: "Approved follow-ups carried out: Value engineering repriced (USD 416) with the washer, interlock plug, UV level bar and labels; To confirm items 7 and 9 updated"
---

# LumaFlow design decisions register

Every design decision still to be made, and every decision made, in one place. Each decision is argued in full in its decision record under `docs/decisions/`; this register is the index Amish works from. The build plan (`docs/05-build-plan.md`) describes the design as it stands and does not list open decisions.

## Open decisions

None. All open decisions were decided on 2026-10-02.

## To confirm when parts are bought

| # | What to confirm | Why it matters | Source |
| --- | --- | --- | --- |
| 1 | The flow sensor and the valve have a 3/8 in push-fit port at each end and a flat face for the saddle, and their port centres match the stem height | The stem adaptors plug straight into them and the saddles steady them | LMF-DDR-003, P6 and P9 |
| 2 | Flow coefficients (Kv) of the flow sensor and the valve | R8 rests on assumed values of 0.35 and 0.25 | LMF-CAL-001 [G1]; LMF-DDR-002 E6 |
| 3 | The heat sink's fin gaps are 7.5 mm or more, with nine fins on 90 x 90 mm | The M4 socket heads of the LED head sit in the gaps | LMF-DDR-003, P3 |
| 4 | The LED board's output bin at 275 nm and its mounting holes (three on a 38 mm circle) | The dose rests on 60 mW per LED; the board screws to the sink | LMF-CAL-001 [B1]; BOM line 4 |
| 5 | The pipe clamp's band and rubber are 3 mm thick or less in total | The tie rods pass 2 mm outside the clamp | LMF-DDR-003, P2 |
| 6 | The stem adaptors are 1/4 BSPP male with a 3/8 in stem, stainless, food-contact | The cap ports are tapped 1/4 BSPP | LMF-DDR-003, P6 |
| 7 | The PTFE liner supplier's reflectance data at 275 nm, wetted | R2 rests on 0.95; plain PTFE gives 45.2 mJ/cm² | LMF-CAL-001 [B8] |
| 8 | Seal materials are food-contact EPDM, the O-ring size (about 61 mm inside, 1.78 mm section) is stocked, and a 0.5 mm food-contact PTFE washer for the window seat (decided 2026-10-02) | Wetted parts (R11) | LMF-DDR-003, P1 and P4; this register, 2026-10-02 |
| 9 | The LED head plug and socket are 6-pin, about 12 mm across (GX12 class), and fit the 12 mm hole in the enclosure floor; the LED bar module fits behind the five 6 x 8 mm segments in the lid | The interlock loop (R12) and the UV level bar (R18) | This register, 2026-10-02; BOM lines 10 and 13 |

## Value engineering

Value-engineering target: USD 340 (a hypothetical control target, not a limit). Estimated cost of the constructable design: USD 416 (USD 76 over the target). Main cost drivers and savings worth trying:

- The largest lines are the six UV-C LEDs (USD 54), the machined 316 lower cap (USD 48), the high-reflectance PTFE liner (USD 45), the tube with its welded sensor boss (USD 38) and the quartz window (USD 32).
- Making the design constructable added USD 64: the welded sensor boss (USD 12 more on the tube line), the retaining ring and seals (USD 12), the threaded ports and stem adaptors (USD 10 more on fittings), the drilled bracket plate and saddles (USD 10 more), the pipe clamps (USD 8), more machining on both caps (USD 9), more fixings (USD 4) and drilling of the heat sink (USD 1), less USD 2 on the sensor line.
- Savings worth trying: a plain PTFE liner instead of the high-reflectance grade (most of USD 45, but the laminar dose falls to 45.2 mJ/cm², inside the 20 % margin, so R2 would be at risk); a clamp-on saddle with a band clamp instead of the welded boss (about USD 10); one machine shop quote for both caps, the tube boss and the holder together; LED prices at quantity, which fall fastest of all the lines.
- The decisions of 2026-10-02 added USD 14, now priced in the BOM: the PTFE window washer (USD 2), the LED head plug, socket and interlock-loop cable (USD 4), the five-segment UV level bar (USD 3) and the labels line (USD 5). Labels printed in-house on vinyl would save most of their USD 5.

## Decisions made

| Date | Decision | Decided by | Record |
| --- | --- | --- | --- |
| 2026-09-25 | TRL 2 review items D1 to D9: design for 90 %/cm water with alarm and valve closure below 40 mJ/cm², R3 kept visibly not met; budget to $225; axial LED head with a flat quartz window; 275 nm LEDs; Hall-effect flow sensor; normally closed valve; vertical mounting with upward flow; external certified 24 V adapter; first user a well-water household | Amish: "proceed with all of your recommendations across all batches. Make sure we don't proceed to TRL 4 on any of them." | LMF-DDR-001 |
| 2026-09-25 | TRL 3 items E1 to E8: 316 lower cap and shielded acetal upper cap; 50 mm bore, high-reflectance liner and 1.2 L/min; wall dose sensor; hold the budget and re-price; 15 Hz per L/min flow sensor; R8 excludes the restrictor; upstream pressure limiter; thermal cut-back | Amish: "i accept all your recommendations, go with them across all repos." | LMF-DDR-002 |
| 2026-09-26 | Budget top-up to $340 for the $338.00 concept BOM | Amish: "I am ok with the budget top ups" | LMF-DDR-002, O4 |
| 2026-09-30 | Make the design physically buildable while drawing the build plan | Amish: "If you are realising that the design cannot be built as per concept - fix the design assumptions to match and be physically feasible as you draw the illustrations." | LMF-DDR-003 (accepted on 2026-10-02, below) |
| 2026-09-30 | Outstanding decisions go in this register, not in the build plan | Amish: "don't log outstanding decisions in this build plan - that is not the place for it. that should be in a separate design document logged and named as such" | This register |
| 2026-10-01 | `budget_usd` is a value-engineering target, reported as over or under, not as a limit | Amish: "the budgets are a hypothethical control target to ensure we are thinking along a value engineering lens. its ok to ensure wording reflects that the hypothesis budget was x - the real cost being accrued is y" | LMF-CAL-001 v0.4, LMF-REQ-001 v0.6 |
| 2026-10-02 | Design for construction accepted: the changes P1 to P11 as made, except the window seat of P1, which is settled by the PTFE washer decision below (window on a 0.5 mm PTFE washer, not metal to glass) | Amish: "i approve your recommendations for all 555 open decisions." | LMF-DDR-003, P1 to P11 |
| 2026-10-02 | LED head interlock (R12): a loop wire in the LED head's plug that the controller watches (option a), with the LED cable routed so it is too short for the head to come off while still plugged in | Amish: "i approve your recommendations for all 555 open decisions." | LMF-DDR-003, A1 |
| 2026-10-02 | Window seat: a 0.5 mm PTFE washer under the window (option b), with the optical check re-run for the 0.5 mm larger LED gap; metal on glass only if a TRL 4 pressure test on that seat shows no edge chipping. This differs from the register's earlier recommendation (a) | Amish: "i approve your recommendations for all 555 open decisions." | LMF-DDR-003, A2 |
| 2026-10-02 | Partner for well-water UV transmittance data: a university extension programme for private well owners, with the Texas A&M AgriLife Extension Texas Well Owner Network as the first candidate to approach | Amish: "i approve your recommendations for all 555 open decisions." | LMF-DDR-001 O1, LMF-DDR-002 O1 |
| 2026-10-02 | Dose bar: keep the five-segment bar on the enclosure and add it to the requirements (R18), labelled as UV level relative to the alarm threshold, read from the wall sensor, not as a dose in units | Amish: "i approve your recommendations for all 555 open decisions." | REVIEW 2026-09-26, item 1 |
| 2026-10-02 | Tie rods: acorn nuts, as already in the constructable design | Amish: "i approve your recommendations for all 555 open decisions." | REVIEW 2026-09-26, item 2 |
| 2026-10-02 | Solenoid connector and port collars accepted as drawn in the renders (catalogue-part detail) | Amish: "i approve your recommendations for all 555 open decisions." | REVIEW 2026-09-26, item 3 |
| 2026-10-02 | Hero render: show the cord entering the cabinet wall; keep the adapter in the model and the BOM | Amish: "i approve your recommendations for all 555 open decisions." | REVIEW 2026-09-26, item 4 |
| 2026-10-02 | Labels: a labels line in the BOM now, with a UV-C warning label on the lower cap and on the inside of the enclosure lid, and the product label | Amish: "i approve your recommendations for all 555 open decisions." | REVIEW 2026-09-26, item 5 |
| 2026-10-02 | Idle LED pulse: a firmware rule runs the LEDs for about 10 s every 4 h of idle, with both interlocks and the valve logic unchanged; its effect checked with plate counts at TRL 4 | Amish: "i approve your recommendations for all 555 open decisions." | LMF-PRC-001, open questions |

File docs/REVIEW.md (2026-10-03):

# Review note: LumaFlow

## Session 2026-09-25: /populate to a strong TRL 2 (overnight batch run)

### What was done

- `docs/01-problem.md` (LMF-PRB-001 v0.2): problem (mercury, warm-up, yearly lamp change, silent failure), prior work and standards with inline sources, users and context, constraints, out of scope, open questions. There was no co-design checklist to keep.
- `docs/03-requirements.md` (LMF-REQ-001 v0.2): 16 measurable requirements (R1 to R16) with targets, status against the estimates and planned verification, plus assumptions.
- `docs/02-concept.md` (LMF-PRC-001 v0.2): how it works, 16 numbered components, flow, dose, dose monitor, power, heat, window stress, size and cost estimates, design choices, safety section, open questions.
- `cad/src/concept_media.py`: massing model of the vertical reactor (tube, liner, window, LED board, heat sink, two end caps, flow sensor, photodiode, valve, controller, enclosure, bracket, fittings, adapter) with a 1 L bottle as the scale context, since the unit is sink-cabinet size.
- `media/`: `hero.png`, `concept-blueprint.png`, `.pdf` and `.svg`, `cutaway.png`, `exploded.png` with callouts 1 to 15 matching the BOM, `flow.png` (power flow, all values estimates), `model.glb` and `viewer.html`. Temporary `_views` folders removed.
- `bom/bom.csv`: 16 lines with indicative prices, numbered to match the exploded view (line 16, hardware, is not modeled); `bom/bom-notes.md` updated.
- `README.md`: hero image and links line added before "## Problem"; concept, key components and safety text brought in line with the concept.
- `docs/pdf/`: branded PDFs of the three controlled documents.
- Not changed: `project.yaml` (pitch and problem still fit the numbers), `cad/src/model.py` placeholder (TRL 3 work).

### Key results (estimates, to be checked at TRL 3)

| Quantity | Estimate | Requirement |
| --- | --- | --- |
| Design flow | 2.0 L/min (0.5 gpm), capped by a restrictor | R1 met by design |
| Residence time, Reynolds number | about 2.9 s, about 1,700 (laminar) | |
| UV-C output | about 0.36 W from six 275 nm LEDs at about 13 W electrical | |
| Dose at 90 %/cm UVT | about 40 mJ/cm² (reactor efficiency 0.5 assumed) | R2 met, no margin |
| Dose at 70 %/cm UVT | about 14 mJ/cm² | **R3 not met** |
| Power while flowing, standby | about 21.6 W, about 0.3 W | R9 met |
| Energy | about 10 Wh per day, about 3.8 kWh per year | |
| Water temperature rise | about 0.09 K | |
| Quartz window stress at 8 bar | about 4.5 MPa at 6 mm (about 18 MPa at 3 mm) | R7 met on estimate |
| Envelope | about 240 x 75 x 325 mm without the adapter | R14 met |
| Parts cost | about $217 | **R16 not met, about $17 (9 %) over** |

Requirements not met or unverified:

- **R3 not met:** at the NSF/ANSI 55 test water quality the dose is about a third of the target and below even the Class B level.
- **R16 not met:** about $217 against $200.
- **R2 met with no margin:** it rests on an assumed reactor efficiency of 0.5, the largest uncertainty in the concept.
- **R8 (pressure drop) and R10 (LED temperature) unverified.**

### Proposed, awaiting Amish

All nine items below were later decided by Amish, 2026-09-25: go with recommendation (LMF-DDR-001, D1 to D9).

1. **Design water quality and dose target.** Option A: design for 90 %/cm UVT, alarm and close the valve below 40 mJ/cm², and keep R3 visibly not met. Option B: meet 40 mJ/cm² at 70 %/cm and 2 L/min with about 17 LEDs, about 40 W and about $100 more in LEDs alone. Option C: six LEDs plus a proportional valve that limits flow to about 0.7 L/min in poor water. Recommendation: A, with C as a later upgrade.
2. **Budget.** Options: (a) raise `budget_usd` to $225; (b) drop the shutoff valve and rely on the alarm alone (about $205, still over, and weaker fail-safe); (c) find cheaper LEDs or machine the end caps in-house to reach $200. Recommendation: (a), because the valve is the fail-safe. `project.yaml` is unchanged.
3. **Axial LED head with a flat quartz window** instead of the scaffold's quartz sleeve with LEDs around it. Recommendation: axial.
4. **275 nm LEDs** rather than 265 nm. Recommendation: 275 nm, revisit prices at TRL 3.
5. **Hall-effect flow sensor** as the flow switch and meter, rather than a reed flow switch.
6. **Normally closed outlet valve** that closes on alarm and on power loss.
7. **Vertical mounting with upward flow**, LEDs at the bottom, so air purges at the top.
8. **External certified 24 V adapter** on a GFCI or RCD outlet, so only 24 V DC is at the unit.
9. **First user and partner:** a well-water household with a sediment pre-filter, and a partner that can supply real UVT data.

### Safety concerns

- UV-C exposure to eyes and skin: metal body blocks UV-C; interlocks on the lid and LED head are required.
- False sense of safety: UV removes no chemicals, leaves no residual, fails in cloudy water and is not a full virus barrier at 40 mJ/cm² (adenovirus needs about 186 mJ/cm² for 4 logs). The documents state that LumaFlow is a research and educational prototype, not a certified water treatment device.
- Pressure and leaks at up to 8 bar next to electronics; a cracked window floods the 24 V LED head.
- Mains in a wet cabinet: confined to a certified adapter on a GFCI or RCD outlet.
- LED overheating if left on without flow: firmware must switch off when flow stops.

### Problems and notes

- `project.yaml` pitch and problem were left unchanged; the numbers found do not make them wrong.
- The scaffold BOM listed a quartz sleeve; the concept uses a flat window instead (decision 3). If Amish prefers the sleeve layout, the model and BOM need rework.
- Web search hit its session limit before a few facts could be sourced directly: the fused quartz design stress of about 7 MPa and the 10 to 25 W typical power of mercury point-of-use units are stated as assumptions in LMF-PRC-001 and should be sourced at TRL 3.

### Recommended next step

Review this note and the media, then decide items 1 and 2. If approved, run `/advance-trl3` to check the dose (reactor efficiency, reflectance, mixing), the dose monitor mapping, LED temperature, pressure drop and window stress by calculation, and produce the parametric model and drawing sheet.

## Session 2026-09-25: TRL 3

Amish's instruction for this session (2026-09-25): "proceed with all of your recommendations across all batches. Make sure we don't proceed to TRL 4 on any of them." LumaFlow now claims TRL 3 (proof of concept on paper). TRL 4 is on hold by Amish's instruction.

### What was done

- `docs/decisions/0001-trl2-review-decisions.md` (LMF-DDR-001 v0.1): the nine TRL 2 review items with a recommendation recorded as decided by Amish, 2026-09-25 (D1 to D9), and the items that stay open (O1 to O3).
- `docs/04-calcs/01-sizing.md` (LMF-CAL-001 v0.1) and `docs/04-calcs/sizing.py`: flow and hydraulics; a Monte Carlo ray trace of the reactor (LED emission, window refraction and Fresnel losses, diffuse PTFE and stainless walls, water absorption) giving the fluence field; dose per streamline and RED for plug and laminar flow; dose monitor signal and mapping; switching and run-on; power and energy; a thermal network with a water path; pressure drop, window, sensor window, tube and tie rods; size from the model; cost from the BOM; options for the dose gap, including a bore study that reruns the ray trace at 40 and 50 mm. The script imports the model's `PARAMS`, `levels()` and part volumes and prints every number the note quotes, tagged [A1] to [K1]. It runs in about 30 s.
- `cad/src/model.py`: parametric build123d model (tube, PTFE liner and top disc, quartz window, LED board, heat sink and spreader ring, 316 lower cap, acetal upper cap, tie rods, flow sensor, photodiode, valve, controller, enclosure, bracket, fittings with the 316 outlet insert, adapter), exporting `cad/step/lumaflow-assembly.step`, `reactor.step`, `led-head.step` and matching STL files.
- `cad/src/sheets.py` and `cad/drawings/LMF-DWG-001.svg`, `.pdf`, `.png`: general arrangement at Rev P1, scale 1:5, with overall, port and window heights and cap diameter drawn from the model, and a main-dimensions box. The sheet carries "CONCEPT, NOT FOR FABRICATION" and "PRELIMINARY, NOT FOR FABRICATION". The concept sheet stays LMF-DWG-010, so DWG-001 was the next free number.
- `bom/bom.csv` and `bom/bom-notes.md`: all 16 lines priced with a supplier type; total $249.00 against the new $225 budget.
- `cad/src/concept_media.py` now builds the media from `model.py` with figures from the calc; all media in `media/` were regenerated and checked by eye (the overlapping loss labels on the flow diagram were shortened; the stainless lower cap was recolored so it reads as steel in the cutaway); temporary `media/_views*` folders were deleted.
- LMF-PRB-001, LMF-PRC-001 and LMF-REQ-001 revised to v0.3 (decisions recorded, numbers replaced by LMF-CAL-001, status column from the calc); `README.md` updated to TRL 3 with links; `project.yaml` set to `trl: 3`, `trl_target: 3`, `budget_usd: 225`, with the evidence files listed. PDFs are in `docs/pdf/`.
- Citations: the two facts flagged at TRL 2 are now sourced. The fused quartz design stress is 6.8 MPa (1,000 psi) ([Momentive](https://www.momentivetech.com/materials/fused-quartz-materials/quartz-properties/mechanical-properties)), so R7 now reads 6.8 MPa rather than 7 MPa; tap-scale mercury units draw 13 to 22 W ([VIQUA spec sheet](https://viqua.com/wp-content/uploads/LIT520326_SpecSheet.pdf)), replacing the assumed 10 to 25 W.
- No TRL 4 material exists in the repo (`firmware/`, `electronics/` and `build-log/` hold only placeholders), and none was created.

### Requirements (LMF-CAL-001, Table 5)

8 met, 4 at risk, 3 not met, 1 not verifiable at TRL 3. The dose is judged on the laminar-flow RED, the more pessimistic of the two flow limits.

| ID | Status | Value against target |
| --- | --- | --- |
| R2 | **Not met** | RED 14.7 (laminar) to 19.0 (plug) mJ/cm² at 90 %/cm and 2.0 L/min, against 40. At TRL 2 this was estimated at about 40 and "met" |
| R3 | **Not met** | 6.3 to 7.4 mJ/cm² at 70 %/cm, against 40; kept visibly not met by decision D1 |
| R16 | **Not met** | $249.00 against the new $225 budget |
| R4 | At risk | Far-end photodiode gives about 2.4 nA at 90 %/cm and nothing resolvable at 70 %/cm; with the safe proportional mapping the alarm would close the valve in any water while R2 is not met |
| R5 | At risk | 0.46 s worst-case switch-on at 0.3 L/min, against 0.5 s |
| R8 | At risk | 0.42 bar against 0.5 bar, resting on assumed valve and sensor flow coefficients |
| R10 | At risk | LED board 48.9 °C nominal, 44.1 to 55.9 °C over the water-film range, against 50 °C |
| R15 | Not verifiable at TRL 3 | Service time needs a build |
| R1, R6, R7, R9, R11, R12, R13, R14 | Met | 2 L/min restrictor; LEDs; window 4.46 MPa; 22.6 W and 0.21 W; 316 lower cap and PTFE shielding; light path and interlock by design; 24 V only; 235 x 72 x 322 mm |

Key numbers: only 26.1 % of the 0.36 W of UV-C is absorbed by the water at 90 %/cm, against about 78 % assumed at TRL 2; the PTFE wall (reflectance 0.80 wetted, assumed) takes 49.8 %. The reactor efficiency is 0.77, better than the 0.5 assumed, so the loss is optical, not hydraulic. Six LEDs reach 40 mJ/cm² at 90 %/cm only below 0.64 L/min; a 50 mm bore would give 30.0 to 41.0 mJ/cm² at 2.0 L/min. Energy 3.1 kWh/year against 114 to 193 kWh/year for a mercury unit. Every TRL 2 number in the docs was checked against the script and corrected where it differed (LMF-CAL-001, Table 6).

### Decisions recorded (LMF-DDR-001)

Decided by Amish, 2026-09-25, going with the recommendation: D1 design for 90 %/cm UVT with alarm and valve closure below 40 mJ/cm², R3 kept visibly not met, Option C later; D2 `budget_usd` raised to $225 (set in `project.yaml`, R16 redefined); D3 axial LED head with a flat quartz window; D4 275 nm LEDs; D5 Hall-effect flow sensor; D6 normally closed outlet valve; D7 vertical mounting with upward flow; D8 external certified 24 V adapter on a GFCI or RCD outlet; D9 first user is a well-water household with a sediment pre-filter. The pitch and problem lines were not asked to change and are unchanged. LumaFlow uses no SwapCell pack, so the SwapCell interface v0.3 items and the shared-pack pricing rule do not affect it.

### Proposed, awaiting Amish

Still open from TRL 2 (no recommendation was made):

1. Partner that can supply real well-water UVT data (O1). Portfolio rule: partners are picked per area later. Still Proposed, awaiting Amish (no recommendation).
2. End cap material (O2). Decided by Amish, 2026-09-25: go with recommendation (LMF-DDR-002 E1). The TRL 3 model uses a 316 stainless lower cap (its bore sees full UV-C, and it is the water-cooled heat path; an acetal cap would let the LED board reach 85 °C) and an acetal upper cap shielded by the PTFE liner, top disc and a 316 outlet insert. Recommendation: confirm.

New from TRL 3:

3. **Route to close R2 (most important).** Options: (a) lower the design flow to about 0.6 L/min (R1 falls to a third); (b) 17 LEDs at 2 L/min (53 W, R9 fails, about $99 more); (c) a higher-reflectance liner (0.95 gives 17.3 mJ/cm², not enough alone); (d) a wider bore of about 50 mm (30.0 to 41.0 mJ/cm² at 2 L/min, window about 9.5 mm, larger parts), which can be combined with (c) and a modest flow cut. Recommendation: (d) with (c), as a TRL 3 design iteration re-run through LMF-CAL-001, keeping (a) as the fallback. Until then, D1's rule means the unit would never open its valve. Decided by Amish, 2026-09-25: go with recommendation (LMF-DDR-002 E2).
4. **Dose monitor position (R4).** Move the photodiode from the top disc to the tube wall at mid height (about 20 times more signal at 90 %/cm and a usable signal at 70 %/cm), and keep the proportional mapping, which always under-reads. Recommendation: adopt; optionally add a second reference sensor near the LEDs to separate LED aging from water quality. Decided by Amish, 2026-09-25: go with recommendation (LMF-DDR-002 E3).
5. **Budget (R16).** $249.00 against $225. Options: (a) raise `budget_usd` to $250; (b) cut cost (for example an acetal lower cap, which fails R10 and R11); (c) hold until the R2 route is chosen, since it changes the tube, caps and window. Recommendation: (c), then re-price. `budget_usd` stays at $225. Decided by Amish, 2026-09-25: go with recommendation (LMF-DDR-002 E4).
6. **Flow sensor pulse rate (R5).** Choose a sensor of 15 Hz per L/min or more, halving the worst-case detection time. Recommendation: adopt. Decided by Amish, 2026-09-25: go with recommendation (LMF-DDR-002 E5).
7. **R8 wording.** State that the 0.5 bar excludes the flow restrictor, which absorbs excess supply pressure by design; confirm the valve and sensor flow coefficients from datasheets. Recommendation: adopt. Decided by Amish, 2026-09-25: go with recommendation (LMF-DDR-002 E6).
8. **Pressure limiter and thermal cut-back.** Make an upstream pressure-limiting valve an installation requirement (a 16 bar spike gives 8.9 MPa in the window), and add a board temperature sensor that cuts LED current above 50 °C (R10). Recommendation: adopt both. Decided by Amish, 2026-09-25: go with recommendation (LMF-DDR-002 E7, E8).

### Safety concerns

- **False sense of safety, now larger.** The calculated dose is 14.7 to 19.0 mJ/cm² in clear water, below the 40 mJ/cm² target and near or below the Class B level of 16. Every document says LumaFlow is a research and educational prototype, not a certified water treatment device, and that it must not be relied on as a barrier.
- UV-C exposure to eyes and skin: metal and PTFE block UV-C in the model; interlocks on the lid and LED head are required.
- Pressure: the window has margin at 8 bar but not at a 16 bar spike; an upstream pressure limiter is required. A cracked window floods the 24 V LED head.
- Heat: LEDs stuck on without flow take the board to about 69 °C; firmware must switch off when flow stops, with a thermal cut-back as backup.
- Mains in a wet cabinet: confined to a certified adapter on a GFCI or RCD outlet.

### Recommended next step

TRL 4 is on hold by Amish's instruction; no TRL 4 work was started. The next step is to decide item 3 (route to close R2) and, if Amish wishes, run one more TRL 3 design iteration: rerun LMF-CAL-001 with the chosen bore, reflector and flow, move the dose sensor (item 4), and re-price the BOM (item 5). For reference only, TRL 4 would need: a bench reactor built from the BOM, a measured wetted PTFE reflectance and LED output at 275 nm, a lab test report (TST, `environment: lab`) with collimated-beam and flow-through biodosimetry against the dose model, pressure and leak tests of the window and caps, LED board temperature under continuous flow, flow switching timing on a firmware sketch, and build-log entries.

## Session 2026-09-25: recommendations accepted

Amish wrote on 2026-09-25: "i accept all your recommendations, go with them across all repos." Every open item with a recommendation is now decided by Amish, 2026-09-25: go with recommendation, recorded in `docs/decisions/0002-recommendations-accepted.md` (LMF-DDR-002 v0.1). TRL 4 remains on hold.

### Decisions applied and what changed

| # | Decision | Before | After |
| --- | --- | --- | --- |
| E1 | End caps: 316 lower, PTFE-shielded acetal upper (confirm) | Proposed | Decided; no geometry change |
| E2 | Route to close R2: 50 mm bore with a high-reflectance liner and a modest flow cut | 25 mm bore, liner 0.80, 2.0 L/min; RED 14.7 to 19.0 mJ/cm² at 90 %/cm | 50 mm bore, liner 0.95, 1.2 L/min; RED 51.9 to 76.3 mJ/cm² (R2 met) |
| E2 | Consequential geometry | Tube 40 mm OD, caps 60 mm, window 32 x 6 mm, sink 64 mm, M4 rods; 235 x 72 x 322 mm | Tube 65 mm, caps 90 mm, window 57 x 10 mm, sink 90 mm, M5 rods; 277 x 100 x 322 mm |
| E3 | Dose sensor in the tube wall at mid height | Top disc; 2.4 nA at 90 %/cm, unresolved at 70 %/cm | Wall, Z = 166 mm; 16.3 nA and 0.38 nA; alarm below about 89 %/cm |
| E4 | Budget: hold, then re-price | BOM $249.00, `budget_usd` 225 | BOM $338.00, `budget_usd` 225 (unchanged; figure now open as O4) |
| E5 | Flow sensor 15 Hz per L/min | 0.46 s worst-case switch-on | 0.24 s (R5 met) |
| E6 | R8 excludes the restrictor | 0.42 bar at 2.0 L/min | 0.15 bar at 1.2 L/min (R8 met, Kv assumed) |
| E7 | Pressure limiter as an installation requirement | Assumption only | New R17: limiter at 4 bar or less; window 6.18 MPa at an 8 bar transient |
| E8 | Thermal cut-back above 50 °C | Board 44.1 to 55.9 °C (R10 at risk) | NTC on the board; 37.1 to 44.8 °C (R10 met) |

Files changed: `cad/src/model.py` and the STEP and STL exports; `cad/src/sheets.py` and LMF-DWG-001 (Rev P1 to P2); `cad/src/concept_media.py` and all of `media/` (concept sheet LMF-DWG-010 Rev P2; temporary `_views` folders deleted); `bom/bom.csv` and `bom/bom-notes.md`; `docs/04-calcs/sizing.py` and LMF-CAL-001 v0.2 (wall-sensor ray trace, new flow limits, bore study removed as no longer needed); LMF-PRB-001, LMF-PRC-001 and LMF-REQ-001 to v0.4; LMF-DDR-001 to v0.2; `project.yaml` (DDR-002 added to the evidence; `trl: 3`, `trl_target: 3`, `budget_usd: 225`); `README.md` (concept, components, safety, and new sections on concept rationale, burning platform, where it could be used and what sparked the idea); PDFs in `docs/pdf/`.

### Requirement status (LMF-CAL-001 v0.2)

13 met, 2 not met, 1 at risk, 1 not verifiable at TRL 3, of 17 (before: 8 met, 3 not met, 4 at risk, 1 not verifiable, of 16).

| ID | Status | Value against target |
| --- | --- | --- |
| R3 | **Not met** (accepted by D1) | 17.4 to 21.8 mJ/cm² at 70 %/cm against 40 |
| R16 | **Not met** | $338.00 against $225 |
| R4 | At risk | Wall signal 16.3 nA at 90 %/cm, 0.38 nA at 70 %/cm; mapping and 1 s fail-safe need firmware and test |
| R15 | Not verifiable at TRL 3 | Service time needs a build |
| R1, R2, R5 to R14, R17 | Met | 1.2 L/min; RED 51.9 to 76.3 mJ/cm²; 0.24 s; window 6.18 MPa; 0.15 bar; 22.6 W and 0.21 W; board up to 44.8 °C; 277 x 100 x 322 mm; limiter at 4 bar |

Notes: R2 rests on the assumed liner reflectance of 0.95 (plain PTFE gives 46.3 mJ/cm², still above 40 but inside the 20 % margin) and on the organism's response at 275 nm. The window margin at 8 bar is now 9 % (6.18 against 6.8 MPa), which is why R17 matters.

### Still awaiting Amish

1. **Partner with real well-water UVT data (O1).** No recommendation; stays Proposed, awaiting Amish.
2. **Budget figure after re-pricing (O4, new).** $338.00 against $225. Options: (a) raise `budget_usd` to about $340; (b) keep $225 and cut cost (a plain PTFE liner saves most of $45 but drops the laminar RED to 46.3 mJ/cm², inside the 20 % margin; simpler machined caps); (c) keep $225 and leave R16 visibly not met. No recommendation is recorded as a decision; `budget_usd` stays at $225. **Decided by Amish, 2026-09-26: budget top-up to $340 (option (a)); see the session below.**

### Cross-repo actions

None. LumaFlow shares no part or interface with another repo.

### Safety concerns

- The dose is calculated, not measured. Every document keeps the statement that LumaFlow is a research and educational prototype, not a certified water treatment device.
- The larger window has a 9 % stress margin at 8 bar; the pressure limiter (R17) is required, not optional.
- The new wall sensor port is a UV-C and pressure boundary; the saddle, O-ring and quartz window must seal it, and the interlock rules apply.
- UV-C exposure, mains in a wet cabinet and heat: unchanged from the TRL 3 session, with the thermal cut-back added as a backstop.

### TRL 4

TRL 4 remains on hold by Amish's instruction; `trl: 3` and `trl_target: 3` are unchanged, and no TRL 4 material was created. Decided but on hold: measuring the liner reflectance and biodosimetry (E2), firmware for the dose mapping, fail-safe and cut-back (E3, E8), and quotes or purchasing for the re-priced BOM (E4).

## Session 2026-09-26: sources strengthened

Sources in the README were checked against the standard of 2026-09-26 ("Fix the weaker sources"); every kept link (WHO drinking-water fact sheet, USGS domestic wells, CMAJ 2010, patent US 1,151,267) was fetched and confirms its claim.

| Where | Old source | New source |
| --- | --- | --- |
| Region table, Sub-Saharan Africa | WHO drinking-water fact sheet, which gives no regional breakdown | WHO and UNICEF JMP, *Progress on household drinking water, sanitation and hygiene 2000-2022* (2023), p. 14: urban and rural gap in safely managed drinking water of 38 percentage points, the widest of any region |
| Region table, South Asia | None (uncited claim about shallow tube wells) | Row replaced by Bangladesh: Khan et al., *Environmental Science and Pollution Research* (2022), MICS 2019 data, high household *E. coli* contamination linked to 2.28 times the odds of child diarrhea |
| Region table, Andean and rural Latin America | None (uncited) | Row replaced by Latin America and the Caribbean: JMP 2023, p. 14, urban and rural gap of 27 percentage points |
| Region table, Pacific island states | None (uncited claims about rainwater tanks and mercury lamp disposal) | Row rewritten as Pacific islands (Oceania): JMP 2023, p. 14, at least basic drinking water for 93 % of urban and 51 % of rural people in 2022 |

"What sparked the idea" was already on a primary source (patent US 1,151,267 on Google Patents) and is unchanged.

### Budget top-up

Budget top-up to $340: decided by Amish, 2026-09-26 ("I am ok with the budget top ups"). `project.yaml` `budget_usd` is 340 (was 225). `docs/04-calcs/sizing.py` reads the budget from `project.yaml` and was re-run: BOM $338.00, $2.00 under [I1]; R16 now met. Counts: 14 met, 1 not met (R3, accepted by D1), 1 at risk (R4), 1 not verifiable at TRL 3 (R15). Open item O4 is decided.

Files changed: `project.yaml`; `README.md` (budget line, cost sentence, region table); LMF-REQ-001 v0.5 (R16 target $340, met); LMF-CAL-001 v0.3; LMF-DDR-002 v0.2 (O4 decided); LMF-PRC-001 v0.5 and LMF-PRB-001 v0.5 (budget figure); `cad/src/concept_media.py` and `media/` regenerated (concept sheet LMF-DWG-010 Rev P3, key figure now "$338 in parts against the $340 budget"); PDFs in `docs/pdf/`. The margin is only $2.00, so any price rise at quoting reopens R16.

## Session 2026-09-26: product appearance model and photoreal renders

Amish chose this repo for the first batch of product renders on 2026-09-26. This session added an appearance model for photoreal renders; the renders themselves (`media/render-hero.png`, `media/render-exploded.png`) are produced later by the portfolio render pipeline.

### What was done

- `cad/src/product_model.py` (new): `product_parts()` returns 55 parts (37 shell, 8 internal, 1 accessory, 9 context) with colour, material, BOM line, group and explode offset. It imports `PARAMS`, `levels()` and `build_parts()` from `cad/src/model.py`, so every main dimension and interface is unchanged. It also sets `TITLE` and three `RENDER_VIEWS`: hero (with context), exploded, and a detail view without the cabinet so the unit fills the frame.
- What it adds over the massing model:
  - Filleted rims on both end caps, the heat sink base, the enclosure, the bracket plate and clamp rings, the flow switch and valve bodies.
  - A wrapped product label with a wordmark and accent band on the tube, and a yellow UV-C warning label on the lower cap.
  - Acorn nuts and washers on the tie rods; screw heads on the enclosure lid and the bracket.
  - Enclosure split into a rear body and a front lid at a parting-line groove, with a buzzer grille, a cable gland, a status and dose bezel, a lit green status light and a lit dose bar.
  - Flow switch with a teal sensor cap, a flow-direction arrow and a lead; solenoid valve with a coil, a connector, a core nut and a lead; push-fit collets at every port.
  - Dose sensor split into a 316 saddle, a quartz sensor window and an amplifier housing with a lead to the enclosure.
  - Internals for the exploded view: PTFE liner, quartz window, and the LED board with six dark LED packages, a connector and the NTC.
  - Context: a short section of cabinet wall and floor, a chrome angle stop on the cold line, a countertop section with a stainless sink edge, and the drinking-water tap fed by the outlet line.
- UV-C safety in the renders: the LEDs are modeled as dark, unlit packages, and no part suggests visible or exposed UV-C light. Only the status light and the dose bar are emissive.
- `README.md`: hero image now points to `media/render-hero.png`, with an "Exploded render" link added to the links line.
- Previews were checked with the kit's matplotlib renderer (clear parts left out).

### Differences from model.py (appearance only)

1. **Dose bar on the enclosure.** The concept documents name a status light and a buzzer; the appearance model adds a five-segment dose bar beside the status light. Proposed, awaiting Amish. Recommendation: keep it, since it makes the dose monitor legible to a user at a glance and costs little (a few LEDs on the controller module); record it in the requirements if accepted, otherwise remove it from `product_model.py`.
2. **Acorn nuts on the tie rods.** The domed nuts stand about 3.6 mm above the plain nuts in `model.py` (overall height about 301 mm instead of 297 mm). Proposed, awaiting Amish. Recommendation: accept acorn nuts; they cover the rod ends and the change is within R14.
3. **Solenoid connector and port collars.** The valve coil carries a plug-in connector that stands 7 mm in front of the model's valve envelope, and both the flow switch and the valve gain 5 mm port collars and push-fit collets at each end. Proposed, awaiting Amish. Recommendation: accept; they reflect catalog parts of the kind already in the BOM.
4. **Adapter and power cord in the hero.** The 24 V adapter is shown only in the exploded view; in the hero the DC cord leaves the gland and enters the cabinet wall rather than running to the adapter on the floor, to keep the frame on the unit. Proposed, awaiting Amish. Recommendation: accept for the renders; the model, drawing and BOM still place the adapter on the cabinet floor.
5. **Labels.** The product label and the UV-C warning label are not in the BOM. Proposed, awaiting Amish. Recommendation: add a labels line (a few dollars) at the next BOM revision; a UV-C warning label is good practice regardless, but note the budget margin is only $2.00.
6. **Not modeled.** The LED supply cable from the enclosure to the LED head is left out of the appearance model for clarity.

### TRL

This is an appearance model only: no tolerances, no fabrication detail. `trl` stays 3 and TRL 4 remains on hold; no TRL 4 material was created.

## Session 2026-09-27: kit 1.5.0 and image quality

- Kit 1.5.0 synced: STANDARDS v1.5 (sections 12 to 15: product renders, storefront images and image quality, public release, authorship and signing), `.kit/cards.py`, `.kit/image_qc.py`, `.kit/release_gate.py`, issue templates, and the `/render-product` and `/release` commands. `CLAUDE.md` now matches `.kit/CLAUDE.md`.
- Every `media/render-*.png` recaptioned from its original render with the new layout: the title, concept label and repository sit in a band above the render and the view note in a band below it, each line wrapped to the image width, so no text overlaps other text or the render or runs off the image. `media/card.png` and `media/social-preview.png` regenerated with the same rules.
- `python .kit/image_qc.py` and `python .kit/release_gate.py` pass. trl stays 3.

## Session 2026-10-01: design for construction and illustrated build plan (BLD-001)

Run under kit 1.7.0 `/build-plan` with Amish's instructions of 2026-09-30 ("fix the design assumptions to match and be physically feasible as you draw the illustrations"; outstanding decisions go in a separate register) and of 2026-10-01 (budgets are value-engineering targets). This cloud copy has no git, so nothing was committed or pushed. TRL cap respected: no PCB layout, firmware, purchasing list, test plan or build log; the controller is bought modules wired at block level.

### What was done

- Kit 1.7.0 installed (`.kit/`, `.claude/commands/`); `CLAUDE.md` replaced by `.kit/CLAUDE.md`.
- `cad/src/model.py`: constructable model with every fixing and seal, `positions()` for shared hole positions, and 324 build123d constructability checks (`python cad/src/model.py --check`: no overlaps, every joint touching, listed clearances, removal paths for the window and the LED head). All 324 pass. STEP and STL regenerated in `cad/step/` and `cad/stl/`.
- `docs/decisions/0003-design-for-construction.md` (LMF-DDR-003, Draft): every change and its reason, "made under Amish's 2026-09-30 instruction to make the design physically buildable; open for his review".
- `docs/05-build-plan.md` (LMF-BLD-001 v0.1): plain English, components in build order with making sketches, numbered steps, joint close-ups and checks; 16 assembly steps with pictures; first checks; safety stops; tools. No cost section and no open decisions.
- `docs/06-design-decisions.md` (LMF-DEC-001 v0.1): 10 open decisions, 8 items to confirm when parts are bought, a Value engineering section, and the decisions made with Amish's words.
- `cad/src/build_plan_media.py` (new): overview, 11 making sketches LMF-DWG-101 to 111, two layouts (bracket plate holes, end cap sections), 7 joint close-ups, 16 step pictures and the block wiring diagram, all in `docs/05-build-plan/` and `cad/drawings/`.
- `docs/04-calcs/sizing.py` re-run: new G8 (upper cap roof), cost against the value-engineering target. LMF-CAL-001 v0.4, LMF-REQ-001 v0.6, LMF-PRC-001 v0.6 and LMF-PRB-001 v0.6 updated. `bom/bom.csv` lines respecified and lines 17 and 18 added; `bom/bom-notes.md` rewritten.
- Drawing LMF-DWG-001 Rev P4 (`cad/src/sheets.py`); concept media regenerated (`cad/src/concept_media.py`, concept sheet LMF-DWG-010 Rev P4).
- `project.yaml`: `design_state: constructable`; LMF-DDR-003, the build plan, the register, the overview picture and `build_plan_media.py` added to `trl_evidence`; `budget_usd` unchanged at 340. README: links to the build plan and the register, "Building the prototype" section, cost sentence reworded to the value-engineering target.

### Design changes made for construction (LMF-DDR-003)

1. **Window (P1):** the pocket trapped the 57 mm window between a 50 mm bore and a 51 mm seat and had no seal. Now it is open from below; the window is clamped against a 1 mm EPDM gasket by a 316 retaining ring (72 x 51 x 2 mm, six M3 countersunk screws). Open span, window height and LED gap unchanged.
2. **Tie rods (P2):** they ended on the sink with nothing below them. Now M5 studs are threaded 12 mm into the lower cap, with acorn nuts on the upper cap; pitch circle 78 to 80 mm to clear the pipe clamps.
3. **LED head (P3):** four M4 screws from below in the fin gaps into the lower cap; board on three M3 screws; cable slot in the spreader ring.
4. **Tube ends (P4):** tube 204 mm, seated 2 mm into each cap on a face O-ring; 59 mm spigot in the lower cap; liner's top turned down to 56 mm for the upper groove.
5. **Upper cap (P5):** 30 to 40 mm tall; the roof over the liner is 13 mm (2.8 MPa at 8 bar) instead of 3 mm (about 59 MPa).
6. **Ports (P6):** 20 mm bosses tapped 1/4 BSPP with stainless push-fit stem adaptors that plug straight into the flow sensor and valve.
7. **Outlet sleeve (P7):** the 316 insert overlapped the liner by 0.1 mm; now a 17 mm sleeve ending at the liner.
8. **Sensor (P8):** the clamp-on saddle had no clamp; now a 316 boss TIG-welded to the tube, with a 10 x 3 mm window on a washer pressed by an M12 x 1 photodiode holder.
9. **Bracket (P9):** closed printed rings and an unfixed shelf replaced by a 6 mm aluminium plate, two rubber-lined pipe clamps on M8 studs, the enclosure screwed to the plate (27 mm further back) and two printed saddles for the flow sensor and valve.
10. **Enclosure (P10):** body and screw-on lid for the lid interlock.
11. **Floor gap (P11):** 25 mm of air under the fins; the adapter stays on the floor.

### Key results

- Constructability checks: 324 of 324 pass.
- Envelope unchanged: 277 x 100 x 322 mm (R14 met). Dose, dose monitor, power, pressure drop and window stress unchanged.
- Value-engineering target: USD 340. Estimated cost of the constructable design: USD 402 (USD 62 over the target); the concept was $338.00.
- Requirement status: 13 met, 1 not met (R3, accepted by D1), 1 at risk (R4), 1 not verifiable at TRL 3 (R15), and R16 over its value-engineering target by USD 62.

### Proposed, awaiting Amish

All listed in `docs/06-design-decisions.md`. New this session: accept LMF-DDR-003 (recommendation: accept); how the LEDs are stopped when the LED head is off (recommendation: a loop wire in the head's plug); what the window bears on (recommendation: lapped stainless ring for the first prototype). Carried over: O1 partner (no recommendation), the five appearance-model items of 2026-09-26, and the idle LED pulse question.

### Safety concerns

- UV-C: the build plan holds LED power until the reactor is closed, the lid switch is proven and everyone nearby wears UV-C eyewear; the LED head interlock is still an open decision.
- Pressure: an 8 bar leak test of the reactor alone comes before any wiring; the window bears on a lapped ring, and the pressure limiter (R17) stays an installation requirement.
- The window stress margin at 8 bar is still 9 % (6.18 against 6.8 MPa); the thicker upper cap roof removes a weak point the concept had.
- LumaFlow stays a research and educational prototype, not a certified water treatment device; the plan says so in its safety box and stop S6.

### Recommended next step

Amish reviews LMF-DDR-003 and open decisions 1 to 3 in the register. TRL 4 stays on hold; the build plan is ready for it when Amish lifts the cap.

## Session 2026-10-02: open decisions decided

Amish, 2026-10-02: "i approve your recommendations for all 555 open decisions." The recommendations written for this repo's open decisions are recorded as decided.

### Decisions recorded

10 decisions, moved from "Open decisions" to "Decisions made" in the register (LMF-DEC-001 v0.2):

1. Design for construction P1 to P11 accepted as made, except the window seat of P1, which decision 3 changes (LMF-DDR-003 accepted with that exception).
2. LED head interlock (R12): a loop wire in the LED head's plug, with the LED cable too short for the head to come off while still plugged in.
3. Window seat: a 0.5 mm PTFE washer under the window, with the optical check re-run for the 0.5 mm larger LED gap; metal on glass only if a TRL 4 pressure test shows no edge chipping. This reverses the register's earlier recommendation (a).
4. Partner: a university extension programme for private well owners; the Texas A&M AgriLife Extension Texas Well Owner Network is the first candidate to approach.
5. Five-segment bar kept and added to the requirements as R18, labelled as UV level relative to the alarm threshold, not as a dose.
6. Acorn nuts on the tie rods (already in the design).
7. Solenoid connector and port collars accepted as drawn.
8. Hero render shows the cord entering the cabinet wall; the adapter stays in the model and BOM.
9. A labels line in the BOM now: UV-C warning labels on the lower cap and inside the enclosure lid, and the product label.
10. Idle pulse: the LEDs run for about 10 s every 4 h of idle, interlocks and valve logic unchanged; plate counts at TRL 4.

### Documents changed

- `docs/06-design-decisions.md`: LMF-DEC-001 v0.2
- `docs/decisions/0001-trl2-review-decisions.md`: LMF-DDR-001 v0.3
- `docs/decisions/0002-recommendations-accepted.md`: LMF-DDR-002 v0.3
- `docs/decisions/0003-design-for-construction.md`: LMF-DDR-003 v0.2 (accepted with the window seat exception; status kept Draft)
- `docs/01-problem.md`: LMF-PRB-001 v0.7 (partner)
- `docs/02-concept.md`: LMF-PRC-001 v0.7 (enclosure, idle pulse, partner)
- `docs/03-requirements.md`: LMF-REQ-001 v0.7 (R12 status; R18 added)
- `docs/04-calcs/01-sizing.md`: LMF-CAL-001 v0.5 (requirement table; no figure changed)
- `README.md` and `bom/bom-notes.md` (not controlled)

### Follow-up actions to carry approved decisions into the design

1. Decision 2: add the loop wire pair to the LED head plug and set the LED cable length in the model, the wiring section of the build plan (section 3.12.1) and its pictures, and add a first check that removing the LED head stops the LEDs (model, pictures).
2. Decision 3: add the 0.5 mm PTFE washer under the window in the model (lower cap stack, P1), the window stack section of the build plan (section 3.5, step 3 no longer laps the seat for metal to glass) and its pictures (model, pictures).
3. Decision 3: re-run LMF-CAL-001 section B (ray trace and dose) and the window stress for the 0.5 mm larger LED gap (calculations).
4. Decision 3: add the PTFE washer to BOM line 17 (BOM).
5. Decision 4: approach the Texas A&M AgriLife Extension Texas Well Owner Network; nothing is agreed (docs).
6. Decision 5: replace the single status light pipe in the enclosure lid with a five-segment bar in the model and BOM line 13, and add R18 to `docs/04-calcs/sizing.py` at its next run (model, BOM, calculations).
7. Decision 8: re-render the hero on Amish's Mac with the cord entering the cabinet wall (pictures).
8. Decision 9: add a labels line to the BOM (UV-C warning label on the lower cap and inside the enclosure lid, and the product label) and show the labels in the build plan pictures (BOM, pictures).
9. Decision 10: write the idle pulse rule into the firmware notes when firmware is written at TRL 4, and add the about 6 h a year of LED time to the LED life estimate (calculations).

### Points found in the review

- The value-engineering note offers a plain PTFE liner as a saving, but it drops the dose to 46.3 mJ/cm2 and puts R2 at risk, so it is not a like-for-like saving.
- Cost is $402 against the $340 target, $62 (18 percent) over, and the labels line (item 9) adds a few dollars more.
- The 2026-09-26 review note says the budget margin is only $2.00; that predates the constructable design and is now out of date.

## Session 2026-10-02: approved follow-ups carried out

Amish, 2026-10-02: "497 follow-up actions that need CAD, drawing, picture, BOM or calculation work ... APPROVED CHANGES, COMPLETE THESE", and for renders "Photoreal renders are out of date in most repos ... COMPLETE THESE". This cloud copy has no git, so nothing was committed or pushed. TRL cap respected: no firmware, PCB, test plan or build log.

### Follow-ups and what was done

1. **Decision 2, LED head interlock: done.** `cad/src/model.py` has the LED head cable (a flat run through the spreader ring slot, then a 6-core round cable about 95 mm from the board to a 6-pin plug in a 12 mm socket in the enclosure floor; two cores are the interlock loop). New checks: the cable covers its 89.8 mm route with 5.2 mm slack, and it is 39 mm short of letting the head slide clear of the cap while plugged in. Build plan sections 3.6, 3.12 and 3.12.1 (wiring, Table 2), steps 5, 6 and 14, Figure 24 (new joint-08), the wiring diagram, and a new first check "LED head interlock" (R12). Safety box and stop S3 now say "plugged in".
2. **Decision 3, PTFE window washer in the model and plan: done.** A 0.5 mm PTFE washer (57 x 51 mm) sits between the retaining ring and the window; the LED gap is 1.3 mm (was 0.8); the pocket shoulder moved to 13.5 mm; the inlet stays 19 mm up the cap. Build plan section 3.5 (no lapping for metal to glass), step 4, Figure 10 (joint-01), making sketches LMF-DWG-103 and 104 (Rev P2), cap-sections picture.
3. **Decision 3, optics and window stress re-run: done.** LMF-CAL-001 v0.6, section B: RED at 90 %/cm 50.9 (laminar) to 74.9 (plug) mJ/cm² (was 51.9 to 76.3), 84.8 % of the LED output enters the water (was 87.0 %), the flow limit for the 20 % margin is 1.26 L/min (was 1.30). Window stress unchanged at 6.18 MPa: the washer's bore equals the ring's 51 mm.
4. **Decision 3, BOM line 17: done.** PTFE washer added, line 17 now USD 14.
5. **Decision 4, approach the Texas A&M AgriLife Extension Texas Well Owner Network: not done.** Contacting an outside organisation is Amish's action; nothing has been sent and nothing is agreed. LMF-PRB-001 v0.8 says so. Draft first message for Amish to send if he wishes:

   > Subject: UV transmittance data for private well water, open-source UV-C LED disinfection prototype
   >
   > I run an open-source hardware project, LumaFlow, a paper-stage design for an under-sink UV-C LED reactor for private well owners. Its dose depends on the water's UV transmittance at about 275 nm, which we have only as published ranges. Would the Texas Well Owner Network be open to sharing anonymised UVT, iron, manganese and turbidity results from household well samples, or to measuring UVT on a small set of samples at a later stage? The design is a research and educational prototype, not a certified water treatment device. The documents are open at github.com/BoujeeEnjinia1701/lumaflow. Amish Chadha

6. **Decision 5, five-segment bar and R18: done.** The single light pipe in the lid is replaced by five 6 x 8 mm segments (model, BOM line 13 now USD 9, LMF-DWG-111 Rev P2, Figure 22 (new joint-09), step 14, wiring diagram). `docs/04-calcs/sizing.py` new C6: segments light at 1.0, 1.1, 1.2, 1.3 and 1.5 times the alarm signal; three of five lit at 90 %/cm with rated LEDs; the last goes out where the alarm trips (88.7 %/cm). R18 added to section K.
7. **Decision 8, hero with the cord entering the cabinet wall: scene prepared.** `cad/src/product_model.py` routes the DC cord from the gland down under the bracket plate into the cabinet wall through a grommet; the adapter is in the accessory group (exploded view only) and stays in the model and BOM. The photoreal render itself is made on Amish's Mac.
8. **Decision 9, labels: done.** New BOM line 19 (USD 5): UV-C warning labels on the lower cap front and inside the lid, and the product label on the enclosure's right side. All three are in the model (with contact checks) and shown in the overview, step 4, step 13, Figure 22 and LMF-DWG-111; text in build plan section 3.13.
9. **Decision 10, idle pulse: calculation part done; firmware part not done.** E6: about 59 s a day, 6.0 h a year of LED time, 0.28 Wh a day; E4: LED on-time 92 h a year, 10,000 h in 108 years (was 116); F7: a pulse warms the still head by 0.16 K. The firmware notes are TRL 4 work and wait for the cap to lift.

### Requirement status changes (LMF-CAL-001 v0.6, LMF-REQ-001 v0.8)

- R18: Not verifiable at TRL 3 to **Met** (by design, C6).
- R12: Met, now shown in the model and the build plan (was "not yet in the model or build plan").
- R2 still met (50.9 mJ/cm², 27 % margin, was 30 %); R3 still not met (17.0 to 21.3); R4 still at risk (wall signal 13.4 nA at 90 %/cm, 0.19 nA at 70 %/cm; the sub-nanoampere figure moves between runs); R10 still met (37.3 to 45.1 °C).
- R16: over the value-engineering target by USD 76 (was 62).
- Counts: 14 met, 1 not met (R3), 1 at risk (R4), 1 not verifiable (R15), R16 over target.
- R15's target names a status LED; run, fault and service due are now shown on the UV level bar.

### Cost and mass

Value-engineering target: USD 340. Estimated cost of the constructable design: USD 416 (USD 76 over the target). Added on 2026-10-02: washer USD 2, LED head plug, socket and cable USD 4, UV level bar USD 3, labels USD 5; each with a catalogue basis in `bom/bom.csv`. Mass (new, H2): 4.97 kg dry, 5.44 kg full of water, adapter about 0.2 kg extra.

### Documents changed and new versions

- `cad/src/model.py` (500 constructability checks, all pass; was 324), STEP and STL in `cad/step/` and `cad/stl/`
- `bom/bom.csv` (19 lines), `bom/bom-notes.md`
- `docs/04-calcs/sizing.py` and `docs/04-calcs/01-sizing.md`: LMF-CAL-001 v0.6
- `docs/03-requirements.md`: LMF-REQ-001 v0.8
- `docs/02-concept.md`: LMF-PRC-001 v0.8
- `docs/01-problem.md`: LMF-PRB-001 v0.8
- `docs/06-design-decisions.md`: LMF-DEC-001 v0.3 (value engineering repriced; To confirm item 9 added)
- `docs/05-build-plan.md`: LMF-BLD-001 v0.2 (25 components, Table 1 rows for the interlock, bar and labels, new first checks for R12 and R18)
- `cad/src/sheets.py`: LMF-DWG-001 Rev P5; making sketches LMF-DWG-103, 104, 105 and 111 Rev P2 (the others stay P1)
- `cad/src/concept_media.py`: concept sheet LMF-DWG-010 Rev P5 and all concept media
- `cad/src/build_plan_media.py`: overview, cap sections, joints 1 to 9 (8 and 9 new), steps 1 to 16, wiring, sketches 101 to 111
- `cad/src/product_model.py`: rebuilt on the constructable design
- `README.md`

### Appearance model (`cad/src/product_model.py`), proposed, awaiting Amish

Rebuilt from the model's own solids: the welded sensor boss and holder, the bracket plate, saddles and pipe clamps, the 40 mm upper cap, the LED head cable and plug, the lid with the five-segment bar (four segments lit) and the labels. Appearance-only additions: domed tops on the acorn nuts, a printed UV-C symbol on the cap label, a "LumaFlow" wordmark and accent band on the product label, filleted flow switch and valve bodies, lid screw heads, sensor and valve leads, and the DC cord into the wall. The old concept bracket, saddle and status light are gone.

### Cross-repo actions

None.

### Safety concerns

- The LED head interlock now exists in the design, but the cable-length guard depends on the cable being made to 95 mm; a longer replacement cable would defeat it. The build plan says to keep the length.
- The window stress margin stays 9 % at 8 bar; the PTFE washer removes metal-to-glass contact.
- LumaFlow stays a research and educational prototype, not a certified water treatment device.

### Recommended next step

Amish renders the hero, exploded and detail views on his Mac from the exported scenes and regenerates the card and social preview. TRL 4 stays on hold.

## Session 2026-10-02: Photoreal renders redone on the constructable design

Amish, 2026-10-02: "Photoreal renders are out of date in most repos ... COMPLETE THESE". Rendered with Blender Cycles on Amish's Mac (batch F1) from the scenes exported from `cad/src/product_model.py`, captioned with `.kit/photo_caption.py`; `media/card.png` and `media/social-preview.png` regenerated with `.kit/cards.py`. Each raw render was looked at once. No commit or push; `trl` unchanged.

- Views: `media/render-hero.png`, `media/render-exploded.png`, `media/render-detail.png`.
- Re-renders: none.
- Appearance deviations already logged (session "Approved follow-ups carried out", Proposed, awaiting Amish): domed acorn nut tops, printed UV-C symbol on the cap label, "LumaFlow" wordmark and accent band on the product label, filleted flow switch and valve bodies, lid screw heads, sensor and valve leads, and the DC cord into the cabinet wall. Unchanged.
- `python3 .kit/image_qc.py`: 5 images, 0 problems. `python3 .kit/render.py --check`: no FAIL, no storefront warning.
- The "Stale, to regenerate on Amish's Mac" note of the 2026-10-01 session is removed; this work resolves it.

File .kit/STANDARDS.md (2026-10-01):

---
doc_id: OHP-STD-001
title: Documentation and drawing standard
project: Open Hardware Portfolio
doc_type: Standard
version: "1.7"
status: Released
date: 2026-09-30
author: Amish Chadha
license: CC-BY-SA-4.0
revisions:
  - version: "1.0"
    date: 2026-09-24
    author: Amish Chadha
    change: First release of the standard
  - version: "1.1"
    date: 2026-09-24
    author: Amish Chadha
    change: Adopt Technology Readiness Levels (section 9) for project maturity
  - version: "1.2"
    date: 2026-09-24
    author: Amish Chadha
    change: Portfolio phase cap (section 10), concept media standard (section 11), CLAUDE.md guardrails
  - version: "1.3"
    date: 2026-09-24
    author: Amish Chadha
    change: Scale figure, interactive 3D viewer and flow diagrams added to concept media; session slash commands
  - version: "1.4"
    date: 2026-09-26
    author: Amish Chadha
    change: Every sheet and render names the project and its GitHub repository; overall dimensions, ISO centre lines and 300 dpi PNG on sheets; titles name the device and view labels state the viewing direction; optional photoreal renders with Blender
  - version: "1.5"
    date: 2026-09-27
    author: Amish Chadha
    change: Product renders (section 12), storefront images and image quality check (section 13), public release and release gate (section 14), authorship, citation and commit signing (section 15)
  - version: "1.6"
    date: 2026-09-29
    author: Amish Chadha
    change: Licensing metadata with REUSE (section 16), Zenodo DOI and Software Heritage archiving (section 17), release gate checks REUSE and a single CITATION.cff license, archive.py
  - version: "1.7"
    date: 2026-09-30
    author: Amish Chadha
    change: Concept and constructable design states; design decisions register (DEC) kept apart from the build plan; prototype build plan (BLD, section 18) with pictures by component is required TRL 3 evidence; every repo targets TRL 3 during the populate phase; build_views.py; /to-trl3 and /build-plan commands
---

# Documentation and drawing standard

Every project in the portfolio uses this standard, so that each precis, write-up and sketch looks the same and carries its own version history. The standard ships as a kit in each repo's `.kit/` folder. The kit version is in `.kit/KIT_VERSION`.

## 1. Document types and IDs

Every controlled document has a unique ID in the form `PRJ-TYP-NNN`.

- `PRJ` is the three-letter project code listed in section 7.
- `TYP` is the document type code from the table below.
- `NNN` is a sequence number within that project and type, starting at 001.

| Code | Type | Typical file |
| --- | --- | --- |
| PRC | Design precis | `docs/02-concept.md` |
| PRB | Problem statement | `docs/01-problem.md` |
| REQ | Requirements | `docs/03-requirements.md` |
| CAL | Calculation or sizing note | `docs/04-calcs/*.md` |
| DDR | Design decision record | `docs/decisions/*.md` |
| BOM | Bill of materials | `bom/bom.csv` |
| DWG | Drawing or sketch sheet | `cad/drawings/*.svg` |
| BLD | Prototype build plan (section 18) | `docs/05-build-plan.md` |
| DEC | Design decisions register (section 18) | `docs/06-design-decisions.md` |
| TST | Test plan or test report (front matter adds `environment: lab` or `relevant`) | `docs/05-tests/*.md` |

Example: `TBK-PRC-001` is the ThermaBrick design precis.

## 2. Revision scheme

| Artifact | While in draft | When released | Change after release |
| --- | --- | --- | --- |
| Documents | 0.1, 0.2, 0.3 ... | 1.0 | 1.1 for minor edits, 2.0 for a design change |
| Drawings | Rev P1, P2 ... (preliminary) | Rev A | Rev B, C ... |

- Every change to a controlled document adds a row to its revision history before the commit.
- The `version` field in front matter always equals the newest row in `revisions`. The renderer rejects a document where they differ.
- Status is one of `Draft`, `In review`, `Released` or `Superseded`. Draft and In review documents print with a status band on every page.
- Every release is tagged in Git as `<doc_id>/v<version>`, for example `TBK-PRC-001/v1.0`. Drawings are tagged `TBK-DWG-001/revA`.
- Git history is the full audit trail. The in-document revision table is the human-readable summary.

## 3. Document front matter

Every Markdown document under version control starts with this block:

```yaml
---
doc_id: TBK-PRC-001
title: ThermaBrick design precis
project: ThermaBrick
doc_type: Precis
version: "0.1"
status: Draft
date: 2026-09-24
author: Amish Chadha
license: CERN-OHL-S-2.0
revisions:
  - version: "0.1"
    date: 2026-09-24
    author: Amish Chadha
    change: Initial draft
---
```

Quote version numbers so YAML keeps `1.0` as text instead of turning it into a number. List revisions newest last.

## 4. Writing style

- Chicago Manual of Style.
- No em dashes. Restructure the sentence instead.
- Lead each section with its conclusion, then support it.
- SI units throughout, in the form `12 kW`, `450 °C`, `3.2 m`. Imperial values may follow in parentheses.
- Number every figure and table ("Figure 2", "Table 1") and give each a caption.
- State every assumption in the calculation that depends on it.
- Put safety notes in a blockquote starting with **Safety:**.

## 5. Visual identity

| Element | Specification |
| --- | --- |
| Typeface | IBM Plex Sans for text, IBM Plex Mono for code and values (SIL Open Font License, bundled in `.kit/fonts`) |
| Ink | `#111827` |
| Secondary text | `#4B5563` |
| Rules and grid | `#D1D5DB` |
| Accent (one only) | `#0F766E` teal |
| Document page | US Letter, 20 mm margins |
| Drawing sheet | ANSI B landscape (431.8 x 279.4 mm) |
| Footer | Document ID, version, status, license and designmolecule.com on every page |

## 6. Drawing and sketch conventions

- Units are millimeters unless the title block says otherwise.
- Third-angle projection, marked with the symbol in the title block.
- Line weights: visible outlines 0.5 mm, hidden lines 0.25 mm dashed, center lines 0.18 mm chain.
- The title block contains the project, title, drawing number, revision, scale, units, projection, sheet, author, date, material or notes, and license.
- Every sheet and every render names the project and its GitHub repository (from `repo:` in `project.yaml`), at the top of the sheet and in the title block, so a printed or forwarded sheet is never anonymous.
- The drawing title names the device, not only the drawing type (for example "Handheld near-infrared resin scanner: general arrangement").
- Every view label states its scale and viewing direction (for example "Scale 1:1; side elevation looking along +Y"), and every isometric or render states where it is seen from.
- Orthographic views generated with `add_ortho` carry overall dimensions (length and depth on the top view, height on the front view) and ISO 128 centre lines on cylinders; hidden lines are dashed. Tolerances are not shown before TRL 4.
- Sheets are exported as SVG, PDF and a 300 dpi PNG.
- The revision table in the top right of the sheet lists every revision.
- Concept sketches use the same sheet and title block and carry the label "CONCEPT, NOT FOR FABRICATION".
- Geometry comes from `cad/src/*.py` (build123d). Sheets are generated by `.kit/drawing.py` and never edited by hand.

## 7. Project codes

| Code | Project | Code | Project | Code | Project |
| --- | --- | --- | --- | --- | --- |
| TBK | ThermaBrick | PCF | PicoFlow | HLT | HelioLite |
| CCB | CharCube | DRN | DustRunner | TRT | TremorTrace |
| STC | StepCue | FXH | FlexHand | CPD | ColdPod |
| SCL | SunClave | STR | SteamRoot | GGD | GrainGuard |
| SDL | SeedLine | ZBX | ZeerBox | RMS | RootMesh |
| DWD | DewDrive | SSK | StillStack | PPR | PotPress |
| WWT | WaterWatch | LMF | LumaFlow | FCL | FieldCell |
| CNP | ConePro | CVC | CulvertCrawl | EGD | EmberGuard |
| SNF | SnapFrame | CGM | CargoMule | SCM | StepClimber |
| SWC | SwapCell | PLP | PalletPilot | FTK | FlatTrike |
| WWK | WaterWalker | GRR | GrowRider | SSP | SunSpoke |
| SGN | StepGen | PBX | PowerBox | WML | WasteWise-ml |
| WSC | WasteWise Scan | RFE | ReflowEconomy | | |
| OHP | Portfolio-wide | | | | |

## 8. Build and publish

- `python .kit/render.py` checks every controlled document and renders it to `docs/pdf/<doc_id>_v<version>.pdf`.
- `python .kit/drawing.py` (called from each project's `cad/src/sheets.py`) builds drawing sheets as SVG and PDF in `cad/drawings/`.
- The GitHub Action in `.github/workflows/docs.yml` runs the checks on every push and attaches PDFs to a GitHub Release whenever a release tag is pushed.
- Public releases follow section 14: `python .kit/release_gate.py` must pass, and the release tag is `v0.<TRL>.0` (for example `v0.3.0` at TRL 3).

## 9. Technology Readiness Level (TRL)

Each project states its maturity as a Technology Readiness Level on the NASA and US DOE 1 to 9 scale. The TRL rates this specific design, not the underlying technology. A sand battery is commercial elsewhere, but a new sand battery design starts at TRL 2 until evidence shows otherwise.

| TRL | Definition | Evidence the repo must contain |
| --- | --- | --- |
| 1 | Basic principles observed | Problem statement (PRB) |
| 2 | Technology concept formulated | Draft precis (PRC) and requirements (REQ) |
| 3 | Analytical or experimental proof of concept | Calculation note (CAL), working build123d model with STEP export, drawing sheet (DWG), priced BOM with every unit cost filled in, prototype build plan (BLD) with pictures, `design_state: constructable` |
| 4 | Components validated in the lab | Test report (TST) with `environment: lab`, build log entries |
| 5 | Validated in a relevant environment | Test report (TST) with `environment: relevant` |
| 6 | System prototype demonstrated in a relevant environment | Precis at version 1.0 or later with status Released, a drawing at a lettered revision (Rev A or later), and a system-level TST with `environment: relevant` |
| 7 to 9 | Operational demonstration through proven in service | Beyond portfolio scope; claim only with a named deployment partner and evidence |

Rules:

- `project.yaml` records `trl` (current level), `trl_target` (the level the current effort aims for) and `trl_evidence` (the files that support the claim).
- `python .kit/render.py --check` fails if the evidence for the claimed TRL is missing. CI runs this check on every push.
- Documentation alone cannot go past TRL 3. TRL 4 and above require hardware and a test report.
- TRL and visibility are independent. A repo can be public at TRL 3 as a documented design ready to build.
- A change of TRL is recorded in the build log with the date and the evidence that justified it.
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

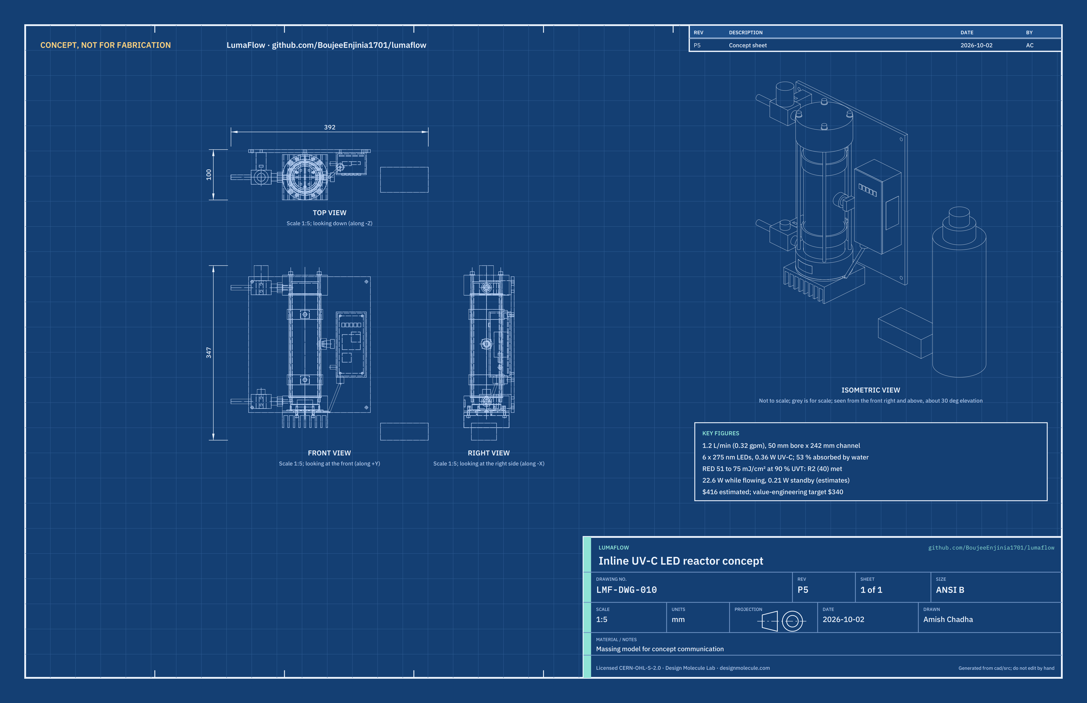
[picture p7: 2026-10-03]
media/concept-blueprint.png

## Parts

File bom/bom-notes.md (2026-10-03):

# BOM notes

Costs are single-unit estimates in USD for a first prototype (2026), priced by supplier type; no quotes have been requested. Item numbers match the exploded view in `media/exploded.png`, the model in `cad/src/model.py`, drawing LMF-DWG-001 Rev P5 and the build plan LMF-BLD-001. Every item is modeled.

- **Total:** Value-engineering target: USD 340 (`budget_usd`, a hypothetical control target, not a limit). Estimated cost of the constructable design: USD 416.00 (USD 76 over the target). `docs/04-calcs/sizing.py` reads this file and prints the total (LMF-CAL-001 v0.6, I1).
- **Change from the concept BOM ($338.00), made to render the design buildable (LMF-DDR-003):** tube with a welded sensor boss $38 (was $26); lower cap $48 (was $42) and upper cap, now 40 mm tall, $19 (was $16); heat sink drilled $14 (was $13); sensor line $24 (was $26, the boss moved to line 1); bracket now a drilled 6 mm aluminium plate with two printed saddles $16 (was $6); fittings with two stainless stem adaptors and the 316 outlet sleeve $24 (was $14); fixings $14 (was $10); new line 17, window retaining ring and seals, $12; new line 18, two pipe clamps, $8.
- **Largest cost:** the six UV-C LEDs (item 4), $54, then the lower cap ($48) and the liner ($45). The cost drivers and savings worth trying are in the design decisions register, LMF-DEC-001.
- **Not in the BOM:** the sediment pre-filter and the pressure-limiting valve (R17) are part of the installation.
- **Decided on 2026-10-02 and now in the BOM (LMF-DEC-001), USD 14 in all:** the 0.5 mm food-contact PTFE washer under the window, line 17, USD 12 to 14 (cut from 0.5 mm PTFE sheet, about USD 10 to 15 for 300 x 300 mm); the LED head cable with a 6-pin GX12-class plug and panel socket carrying the interlock loop, line 10, USD 16 to 20 (catalogue pairs about USD 2 to 4); the five-segment UV level bar in the enclosure lid in place of the single light pipe, line 13, USD 6 to 9 (LED bar module about USD 1 to 2 plus clear filament); and the new labels line 19, USD 5 (two UV-C warning labels and the product label, short-run printed labels at about USD 1 to 2 each). The adapter (item 12) stays in the BOM.
- **Mass:** about 4.97 kg dry and 5.44 kg full of water without the adapter, which adds about 0.2 kg on the floor (LMF-CAL-001 v0.6, H2). Made parts are weighed from the model's volumes and densities, bought parts at typical catalogue masses.
- **Food contact:** every wetted part (items 1, 2, 3, 6, 7, 8, 9 window and washer, 11, 15, 17, including the PTFE window washer) must be food-contact grade. Printed plastics are not used on the water path, and no plastic other than PTFE sees UV-C.
- **Shared parts:** LumaFlow uses no SwapCell pack, so the portfolio rule on pricing shared packs once does not apply.
- LMF-CAL-001 states the assumptions (for example, flow coefficients of items 8 and 11) that depend on these parts.

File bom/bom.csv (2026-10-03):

item | qty | spec | supplier | unit_cost_usd | make_buy | notes
1 Reactor tube | 1 | 316 stainless tube, 65 mm OD x 3 mm wall x 204 mm (200 mm between the caps plus 2 mm into each cap seat), ends faced square; a 316 sensor boss 22 mm diameter x 14 mm TIG-welded on at mid height, then bored 8 mm through boss and wall, 10.2 mm window seat 3.5 mm deep and M12 x 1 thread; passivated after welding | Metals distributor (cut to length) and machine shop (boss) | 38.00 | make | Estimate; the welded boss replaces the clamp-on saddle of LMF-DDR-002, which had no fixing (LMF-DDR-003)
2 High-reflectance PTFE liner and top disc | 1 | Sintered or expanded high-reflectance PTFE tube 59 mm OD x 50 mm ID x 224 mm, the top 22 mm turned down to 56 mm OD, closed by a 56 mm x 3 mm solid top disc; 7 mm outlet hole, 8 mm sensor window hole | Engineering plastics or optical reflector supplier | 45.00 | buy | Estimate; wetted reflectance at 275 nm assumed 0.95 in LMF-CAL-001 and to be measured; plain PTFE (0.80) gives 46.3 mJ/cm² [B8]; turned-down top leaves room for the upper O-ring (LMF-DDR-003)
3 Quartz window | 1 | UV-grade fused silica (JGS1 class) disc, 57 mm diameter x 10 mm, both faces polished | Optics supplier (catalog window) | 32.00 | buy | Estimate; 10 mm sized in LMF-CAL-001 [G4]
4 UV-C LED array | 6 | 275 nm SMD LED (3535 class), about 60 mW optical at 350 mA and about 6.2 V; price per LED, round 44 mm aluminum-core board with an NTC board temperature sensor and three 3.4 mm mounting holes on a 38 mm circle | UV-C LED distributor | 9.00 | buy | Estimate per LED; the NTC feeds the thermal cut-back (R10); output bin must be confirmed
5 Heat sink and spreader ring | 1 | Aluminum finned sink 90 x 90 x 30 mm (9 fins), drilled with four 4.5 mm holes in the fin gaps and three M3 tapped holes; 90 mm OD x 45 mm ID x 3 mm aluminum spreader ring with an 8 mm cable slot; two 0.5 mm thermal pads | Online electronics retailer | 14.00 | buy | Estimate; ring cut from plate; drilling added for the LED head fixing (LMF-DDR-003)
6 Lower end cap | 1 | 316 stainless, 90 mm diameter x 30 mm: window pocket open from below with a 72 mm retaining ring recess, 50 mm bore above a 1 mm gasket shoulder, tube seat with a face O-ring groove around a 59 mm spigot, 20 mm inlet boss tapped 1/4 BSPP, four M5 stud holes, six M3 and four M4 tapped holes | Online CNC machining service or machine shop | 48.00 | make | Estimate for one part from 316 bar; stainless for UV-C exposure and the water-cooled heat path (LMF-DDR-002); window now fitted from below (LMF-DDR-003)
7 Upper end cap | 1 | Acetal (POM) food-contact grade, 90 mm diameter x 40 mm: tube seat with a face O-ring groove, 56 mm liner pocket under a 13 mm roof, 20 mm outlet boss tapped 1/4 BSPP with a bore for the 316 sleeve, four 5.4 mm stud holes | Online CNC machining service or machine shop | 19.00 | make | Estimate; 40 mm tall (was 30) so the roof over the liner pocket is 13 mm, not 3 mm (LMF-DDR-003); sees no UV-C behind the PTFE and the 316 sleeve
8 Hall-effect flow sensor | 1 | Food-grade body, 3/8 in push-fit port at each end, flat back for a saddle, about 0.3 to 6 L/min, pulse output 15 Hz per L/min or more | Online retailer (sensor module) | 10.00 | buy | Estimate; pulse rate chosen for R5 (LMF-DDR-002); pressure drop and K factor to confirm from the datasheet
9 UV-C wall photodiode and amplifier | 1 | UV-grade fused silica sensor window 10 mm x 3 mm with an EPDM washer, photodiode holder threaded M12 x 1 into the tube's sensor boss, SiC UV-C photodiode (TO-46, about 0.06 mm2) with transimpedance amplifier | Sensor distributor and machine shop | 24.00 | buy | Estimate; the boss is now part of line 1 (LMF-DDR-003)
10 Controller and LED driver | 1 | Microcontroller module, 350 mA constant-current driver with dimming input, amplifier, NTC and interlock-loop inputs, valve MOSFET, buzzer and UV level bar outputs, 24 V input fuse; LED head cable: 6-core 0.25 mm² cable about 95 mm from the board to a 12 mm 6-pin circular plug (GX12 class) and panel socket in the enclosure floor, two cores forming the interlock loop | Electronics distributor (modules and connectors) | 20.00 | buy | Estimate; module-based with no custom PCB (R16); USD 4 added for the plug, socket and cable of the LED head interlock loop decided on 2026-10-02 (LMF-DEC-001), from catalogue prices of about USD 2 to 4 for a 6-pin GX12 plug and socket pair
11 Solenoid shutoff valve | 1 | 24 V DC normally closed, food-grade, 3/8 in push-fit port at each end, flat base for a saddle, about 0.2 A | Online retailer (plumbing solenoid) | 12.00 | buy | Estimate; flow coefficient to confirm (Kv 0.25 assumed)
12 24 V power adapter | 1 | 24 V DC, 1.25 A (30 W), safety-certified external adapter, no-load draw 0.1 W or less | Electronics distributor | 10.00 | buy | Estimate; the only mains-voltage part
13 Electronics enclosure | 1 | 3D-printed PETG body and screw-on front lid, lid reed-switch interlock and cable gland; five-segment UV level bar in the lid (five 6 x 8 mm printed light-pipe segments over a 5-LED bar module); back face screwed to the bracket plate with four M4 screws | Self (printed) and electronics distributor | 9.00 | make | Filament plus switch, gland and bar; back sits on the plate (LMF-DDR-003); USD 3 added for the five-segment bar that replaces the single light pipe (R18, 2026-10-02), from catalogue prices of about USD 1 to 2 for an LED bar module plus clear filament
14 Wall bracket | 1 | 6 mm aluminium plate 242 x 270 mm (6061 or 5083 class), two M8 tapped holes for the pipe clamp studs, four M4 tapped holes for the enclosure, four 4.5 mm holes for the saddles, four 5.5 mm wall holes; two printed PETG saddles with M4 heat-set inserts and a cable-tie slot | Metals distributor (cut plate) and self | 16.00 | make | Estimate; replaces the printed backplate with closed rings and a shelf, which could not be fitted or fixed (LMF-DDR-003)
15 Fittings and outlet insert | 1 | Two stainless push-fit stem adaptors, 1/4 BSPP male x 3/8 in stem, with bonded sealing washers; 316 outlet sleeve 9.5 mm OD x 7 mm ID x 17 mm; 3/8 in push-fit fittings, 1 m food-grade tube, cold-line tee, 1.2 L/min flow restrictor | Plumbing supplier | 24.00 | buy | Estimate; threaded ports replace the plain holes (LMF-DDR-003); the 316 sleeve keeps UV-C off the acetal cap; restrictor sets R1
16 Tie rods and hardware | 1 | Four M5 x 260 mm 316 studs with washers and acorn nuts; six M3 x 8 countersunk (retaining ring), four M4 x 16 socket head (LED head), three M3 x 10 low head (LED board), four M4 x 10 pan head (enclosure), four M4 x 10 countersunk (saddles), two M8 x 20 studs (clamps), four wall screws, wire, thermal paste, medium threadlocker | Fastener supplier and self | 14.00 | buy | Estimate; studs now threaded into the lower cap (LMF-DDR-003)
17 Window retaining ring and seals | 1 | 316 stainless ring 72 mm OD x 51 mm ID x 2 mm, six 3.4 mm countersunk holes on a 65 mm circle, flat; PTFE window washer 57 mm OD x 51 mm ID x 0.5 mm; EPDM window gasket 57 mm OD x 50 mm ID x 1 mm; two EPDM face O-rings about 61 mm ID x 1.78 mm, all food-contact grade | Laser-cut stainless supplier and seal supplier | 14.00 | make | The window is clamped from below like a sight glass (LMF-DDR-003); the O-rings seal the tube ends; USD 2 added for the PTFE washer under the window decided on 2026-10-02 (LMF-DEC-001), cut from 0.5 mm food-contact PTFE sheet (about USD 10 to 15 for a 300 x 300 mm sheet)
18 Pipe clamps | 2 | Rubber-lined pipe clamp for 65 mm OD, band and liner 3 mm or less in total, M8 boss | Plumbing or fastener supplier | 4.00 | buy | New (LMF-DDR-003): hold the tube on the bracket plate and open for service
19 Labels | 1 | Two UV-C warning labels (optical radiation warning symbol and "UV-C: do not look into the reactor; disconnect power before removing the LED head"), one on the front of the lower cap and one inside the enclosure lid; one product label (name, 24 V DC rating, research and educational prototype, not a certified water treatment device) on the enclosure side; polyester or vinyl, about 30 x 14 mm and 36 x 30 mm | Label printer (short run) or self (printed vinyl) | 5.00 | buy | New (decided 2026-10-02, LMF-DEC-001); estimate from short-run printed label prices of about USD 1 to 2 per label

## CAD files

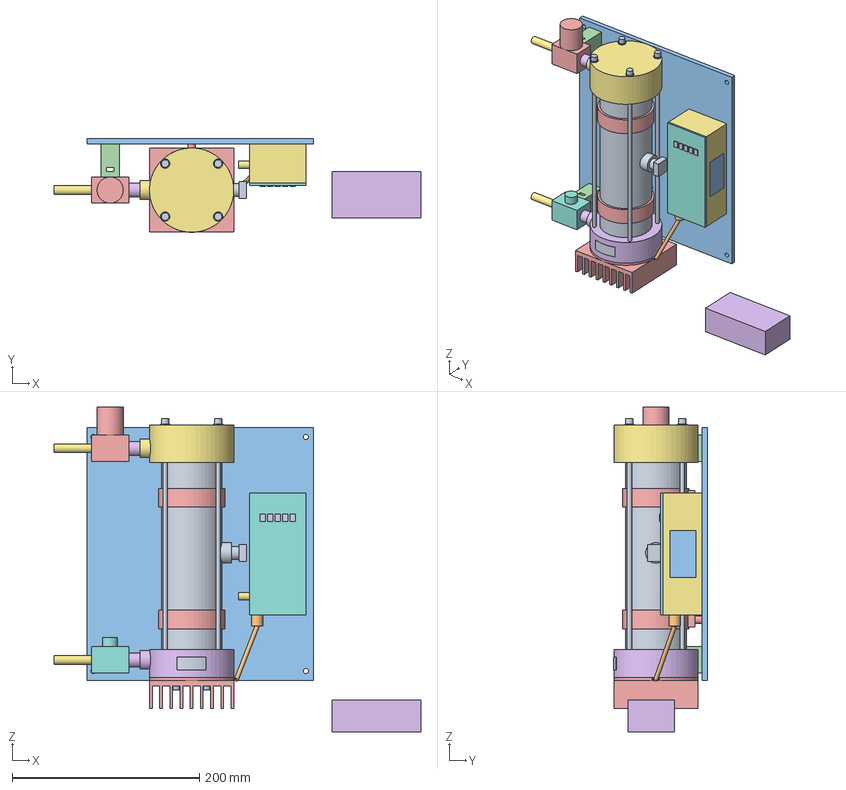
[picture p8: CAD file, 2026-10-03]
cad/step/lumaflow-assembly.step
392.0 x 100.2 x 347.0 mm

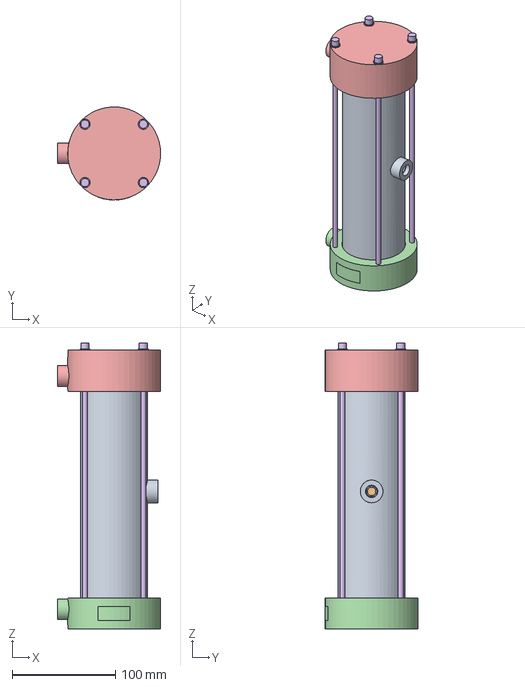
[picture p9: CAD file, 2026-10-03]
cad/step/reactor.step
100.0 x 90.2 x 277.0 mm

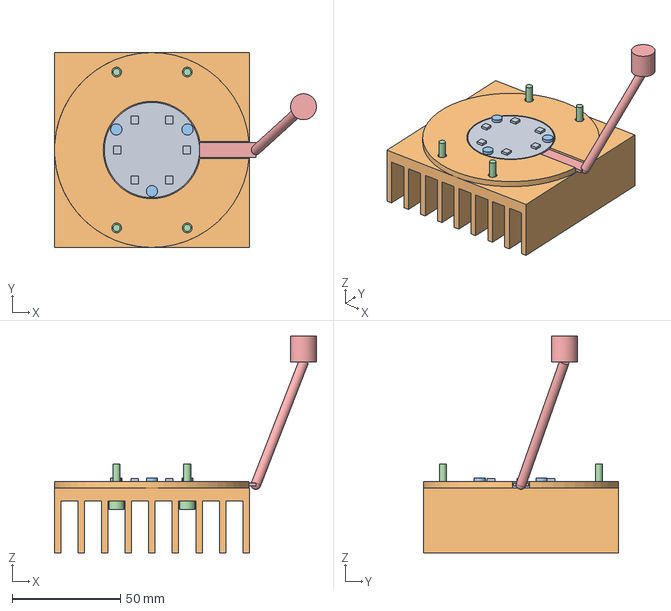
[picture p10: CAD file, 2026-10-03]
cad/step/led-head.step
121.0 x 90.0 x 100.0 mm

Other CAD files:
cad/stl/led-head.stl
cad/stl/lumaflow-assembly.stl
cad/stl/reactor.stl

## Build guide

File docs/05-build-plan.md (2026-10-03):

---
doc_id: LMF-BLD-001
title: LumaFlow prototype build plan
project: LumaFlow
doc_type: Build plan
version: "0.2"
status: Draft
date: '2026-10-02'
author: Amish Chadha
license: CERN-OHL-S-2.0
revisions:
  - version: "0.1"
    date: '2026-10-01'
    author: Amish Chadha
    change: First build plan with pictures by component and step; design made constructable (LMF-DDR-003)
  - version: "0.2"
    date: '2026-10-02'
    author: Amish Chadha
    change: "Decisions of 2026-10-02 carried in: PTFE window washer, LED head cable and plug with interlock loop, five-segment UV level bar, labels; first checks for the interlock and the bar; pictures regenerated"
---

# LumaFlow prototype build plan

**Plan, not yet built.** How to build the first proof-of-concept prototype, component by component. Building and testing to it is TRL 4 work. Decisions still to be made are kept in the design decisions register ([docs/06-design-decisions.md](06-design-decisions.md)), not here.

## 1. What you are building

Figure 1. Every component, pulled apart and numbered in build order

*Figure 1. Every component pulled apart and numbered in build order.*

The prototype is one LumaFlow unit hung on a plate under a kitchen sink: a stainless tube, lined with white PTFE, standing upright between two round end caps, with six UV-C LEDs on a finned heat sink under a quartz window at the bottom, a light sensor in the tube wall, a flow sensor on the way in, a shutoff valve on the way out and a small printed box for the electronics. Water flows up the tube while the LEDs shine up it. Figure 1 shows the 25 components in the order you make or fit them. Eleven are made: the bracket plate, two printed saddles, the stainless lower end cap, the window retaining ring, the drilled heat sink and its spreader ring, four tie rod studs, the tube with its welded sensor boss, the PTFE liner, the acetal upper end cap, the photodiode holder and the printed enclosure. The two caps, the tube boss and the holder need a machine shop with a lathe, a mill and a TIG welder; the rest is sawing, drilling, tapping and 3D printing. Everything else is bought: the window, the PTFE window washer, LEDs, the LED head cable and plug, seals, labels, pipe clamps, push-fit fittings, flow sensor, valve, controller modules and the 24 V adapter. The parts cost about $416 from the bill of materials.

> **Safety:** LumaFlow makes UV-C light, which burns the eyes and skin within seconds to minutes and cannot be seen. Never power the LEDs unless the LED head is on the cap and plugged in, the reactor is closed and the enclosure lid is shut, and wear UV-C blocking eyewear and cover your skin for any bench work with the LEDs. The reactor holds mains water pressure next to electronics: leak test it before any wiring is connected (section 6). Only the certified adapter sees mains voltage; it plugs into a GFCI or RCD-protected outlet. LumaFlow is a research and educational prototype, not a certified water treatment device; do not drink water from it or rely on it as a barrier.

## 2. What changed to make it buildable

The concept showed what the reactor does; some of its parts could not be fitted, fixed, sealed or made as drawn. Each change below keeps what the reactor does (the same water column, LEDs, window, sensor position, flow and size), and all of them are recorded in decision record LMF-DDR-003, which Amish accepted on 2026-10-02 with the window seat changed to a PTFE washer. The last three rows were decided by Amish on 2026-10-02.

*Table 1. Changes from the concept.*

| Component | The concept had | The buildable design has | Why |
| --- | --- | --- | --- |
| Quartz window | Trapped in a pocket narrower above and below than the window; no seal | Pocket open from below; the window goes in from below onto a rubber gasket and is held, on a thin PTFE washer, by a stainless ring with six screws (Figure 10) | It can be fitted and taken out, it seals, and the quartz never bears on bare metal |
| Tie rods | Ending on top of the heat sink with nothing to hold them | Studs screwed into the stainless lower cap, nuts on the upper cap (Figures 15 and 18) | The rods hold the caps together on their own |
| LED head | No fixing; no way out for the LED cable | Four screws from below between the fins into the lower cap; a slot for the cable (Figure 12) | The head comes off for service without opening the water side |
| Tube ends | Butted on flat cap faces, no seal or location | Each end sits 2 mm into a seat on a rubber O-ring; a spigot locates the lower end (Figure 15) | Sealed and located at both ends |
| Upper end cap | 30 mm tall with a 3 mm plastic roof over the water | 40 mm tall with a 13 mm roof (Figure 18) | The 3 mm roof would have been stressed near its breaking point at full pressure |
| Water ports | Plain holes, no thread; 10 mm stubs of tube to the sensor and valve | Threaded ports with stainless stem adaptors that plug straight into the sensor and valve (Figure 25) | Bought fittings, nothing to kink |
| Light sensor mount | A saddle with no clamp; an unsealed window rod | A boss welded to the tube; a small window pressed onto a washer by a screwed holder (Figure 20) | One sealed, welded joint on the pressure wall |
| Wall bracket | Closed rings that only fit before the caps went on; a shelf with no fixing; no wall holes | A drilled aluminium plate, two bought pipe clamps that open, the enclosure screwed to the plate, two saddles for the sensor and valve (Figures 2 to 6) | Every joint is a screw into a tapped hole, and the reactor lifts out after opening two clamps |
| Enclosure | One closed box | A body and a screw-on lid that works the lid switch (Figure 21) | The lid interlock needs a lid |
| Height above the floor | Heat sink fins on the cabinet floor | 25 mm of air under the fins | The fins need free air to cool |
| LED head interlock | Named but not shown | A short cable from the LED head to a plug under the enclosure; two of its wires form a loop that the controller watches (Figure 24) | Unplugging the head stops the LEDs, and the cable is too short for the head to come off while plugged in |
| Status display | One status light in the lid | A five-segment UV level bar in the lid (Figure 22) | Shows the UV level against the alarm point at a glance; it is not a dose reading |
| Labels | None | UV-C warning labels on the lower cap and inside the lid; a product label on the enclosure side | Warn anyone who opens the unit, and name it |

## 3. Making the components

Make and check each component before the assembly step that needs it. Sizes are in millimetres. "Left" and "right" are as seen standing in front of the unit, facing the cabinet wall; the plumbing is on the left and the electronics on the right. Workshop tolerance is 0.5 mm unless a step says otherwise; drawings do not carry tolerances before TRL 4. Wear gloves when handling the PTFE liner and the quartz window, and keep both in clean bags until they are fitted.

### 3.1 Bracket plate

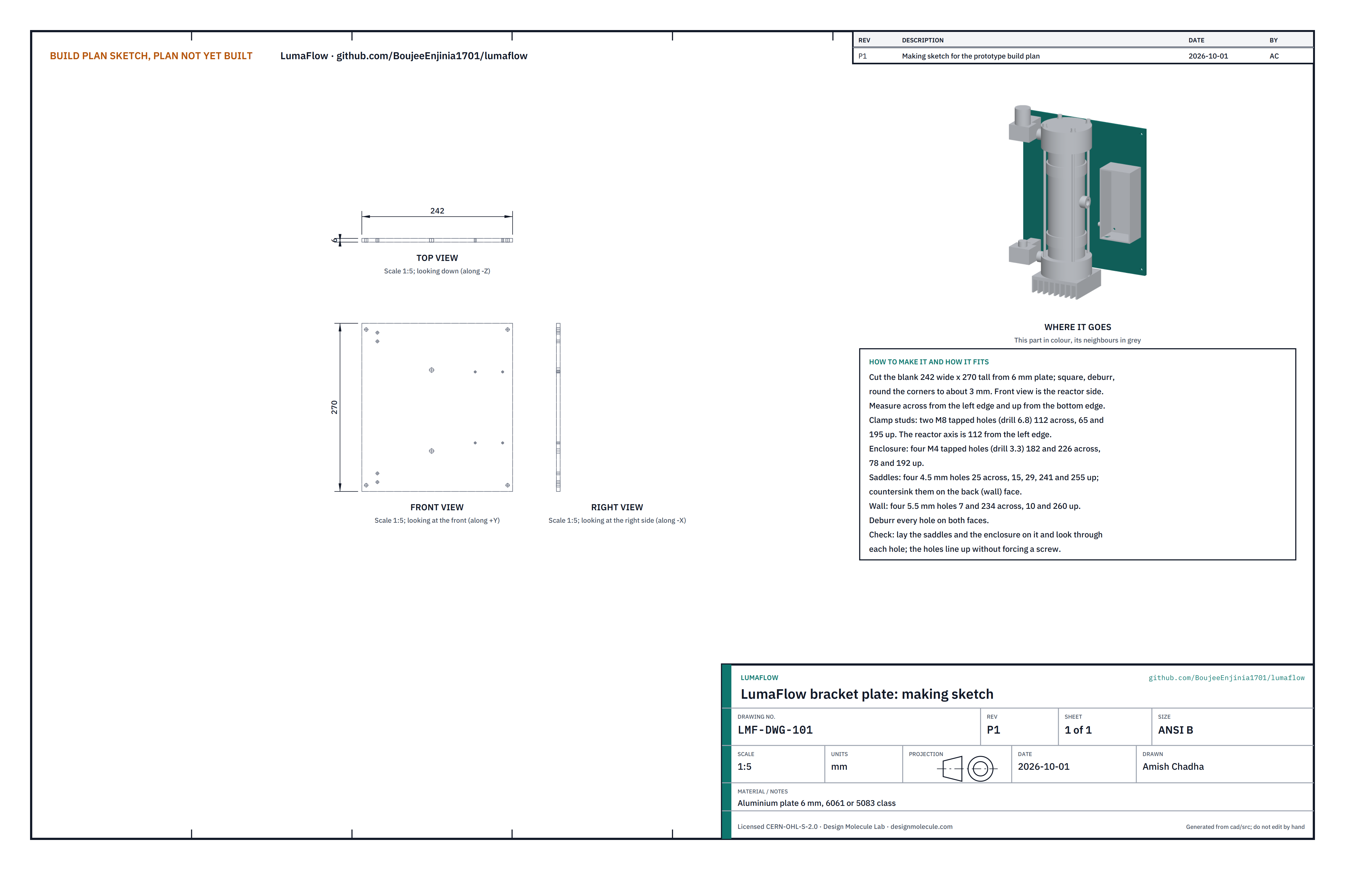
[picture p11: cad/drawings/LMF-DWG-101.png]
Figure 2. Making sketch of the bracket plate


*Figure 2. Bracket plate making sketch (LMF-DWG-101).*

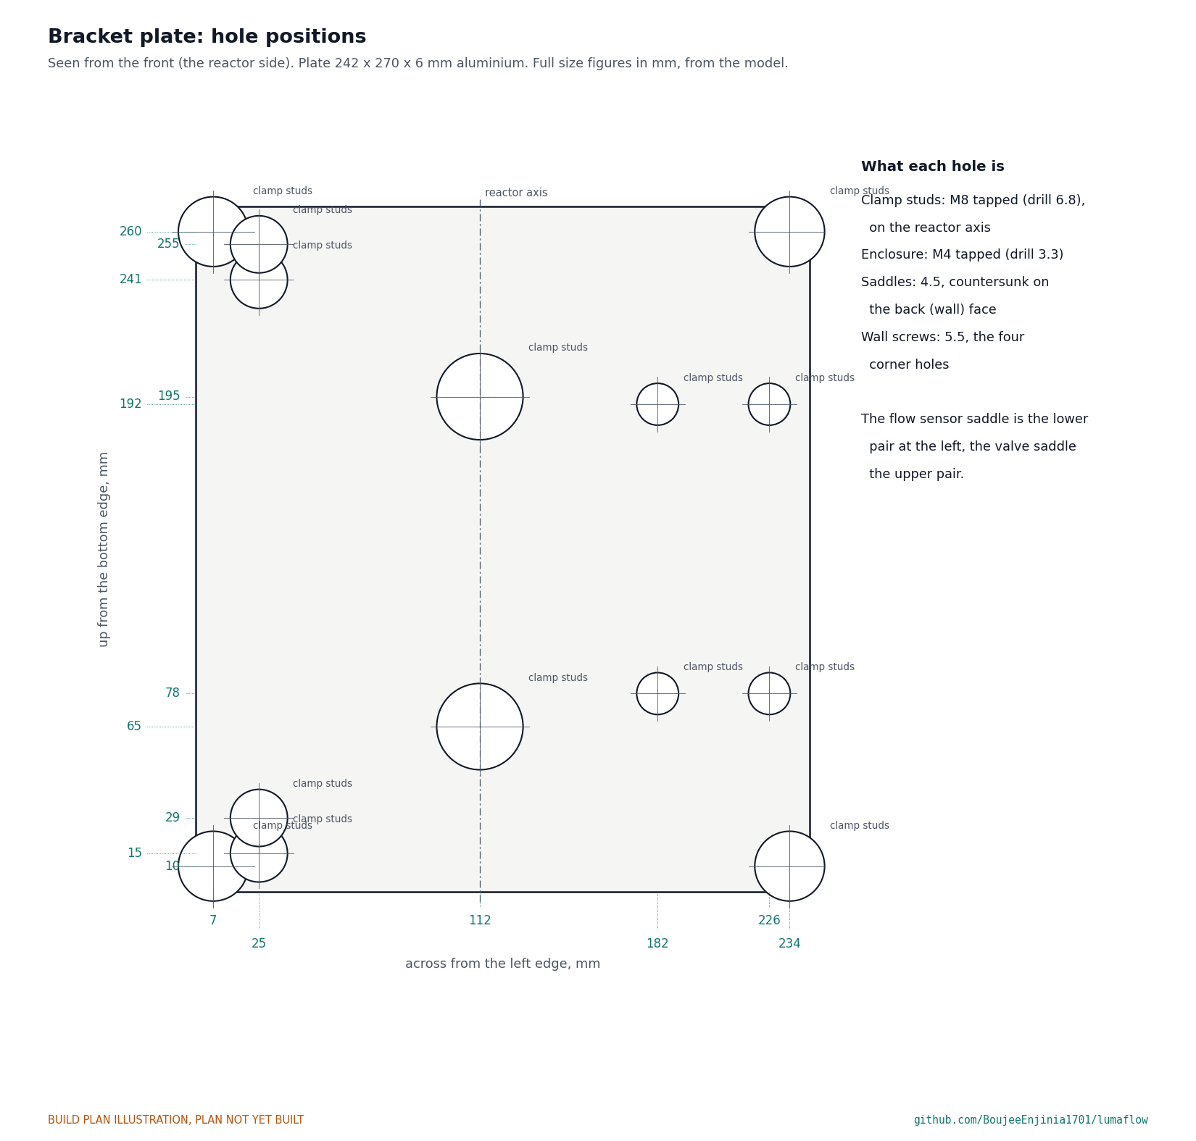
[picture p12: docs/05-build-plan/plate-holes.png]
Figure 3. Hole positions on the bracket plate


*Figure 3. Every hole, full size figures, measured across from the left edge and up from the bottom edge.*

**What it is and what it is made from.** The flat plate that everything hangs on and that screws to the cabinet wall. Aluminium plate 6 mm thick, 6061 or 5083 class, 242 x 270 mm.

**How to make it.**

1. Cut the blank to 242 x 270 mm, square. File the edges and round the corners to about 3 mm. Mark one face as the front (the reactor side).
2. Mark every hole from Figure 3, across from the left edge and up from the bottom edge. The reactor's centre line is 112 from the left edge.
3. Clamp studs: two holes on the centre line, 65 and 195 up. Drill 6.8 mm and tap M8.
4. Enclosure: four holes 182 and 226 across, 78 and 192 up. Drill 3.3 mm and tap M4.
5. Saddles: four 4.5 mm holes 25 across, at 15, 29, 241 and 255 up. Countersink them on the back face.
6. Wall: four 5.5 mm holes at 7 and 234 across, 10 and 260 up.
7. Deburr every hole on both faces.

**How it fits the parts next to it.** The back face sits flat on the cabinet wall on four screws. The saddles sit on the front face at the left (Figure 5), the pipe clamps on their studs on the centre line (Figure 6) and the enclosure's back flat on the front face at the right (section 3.12).

**Check before moving on.** Lay the saddles and the enclosure on the plate and look through each hole: the holes line up without forcing a screw.

### 3.2 Sensor and valve saddles (make 2)

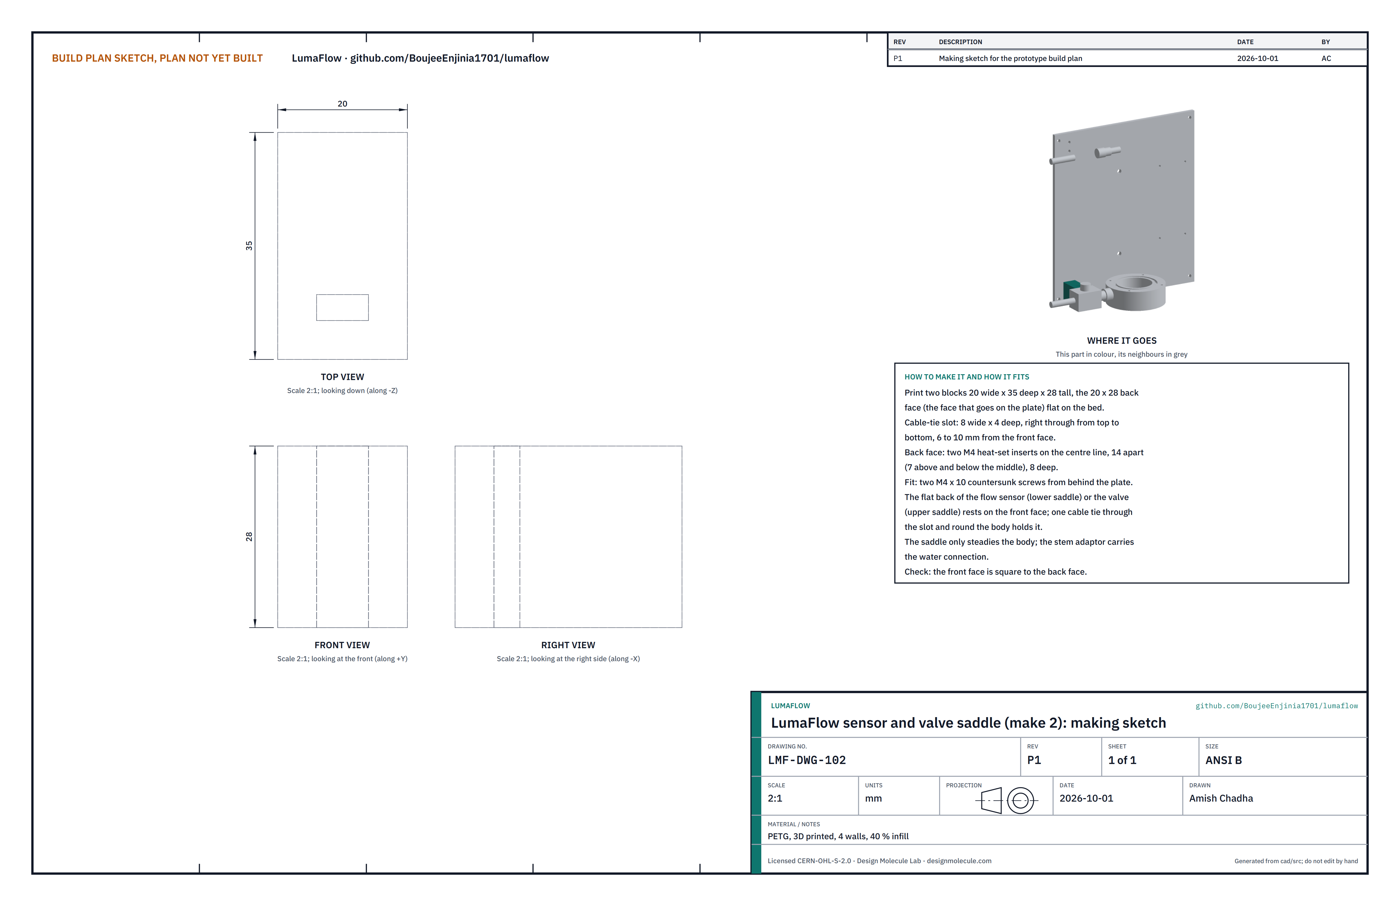
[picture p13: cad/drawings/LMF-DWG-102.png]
Figure 4. Making sketch of the saddle


*Figure 4. Saddle making sketch (LMF-DWG-102).*

**What it is and what it is made from.** A small printed block that steadies the flow sensor (lower saddle) and the valve (upper saddle) so their push-fit joints carry no bending. PETG, printed with 4 walls and 40 % infill.

**How to make it.**

1. Print two blocks 20 wide, 35 deep and 28 tall, with the 20 x 28 back face flat on the bed.
2. Each has a slot 8 wide and 4 deep running from top to bottom, 6 to 10 mm behind the front face, for a cable tie.
3. Press two M4 heat-set inserts 8 deep into the back face, on the centre line, 7 above and 7 below the middle.

**How it fits the parts next to it.**

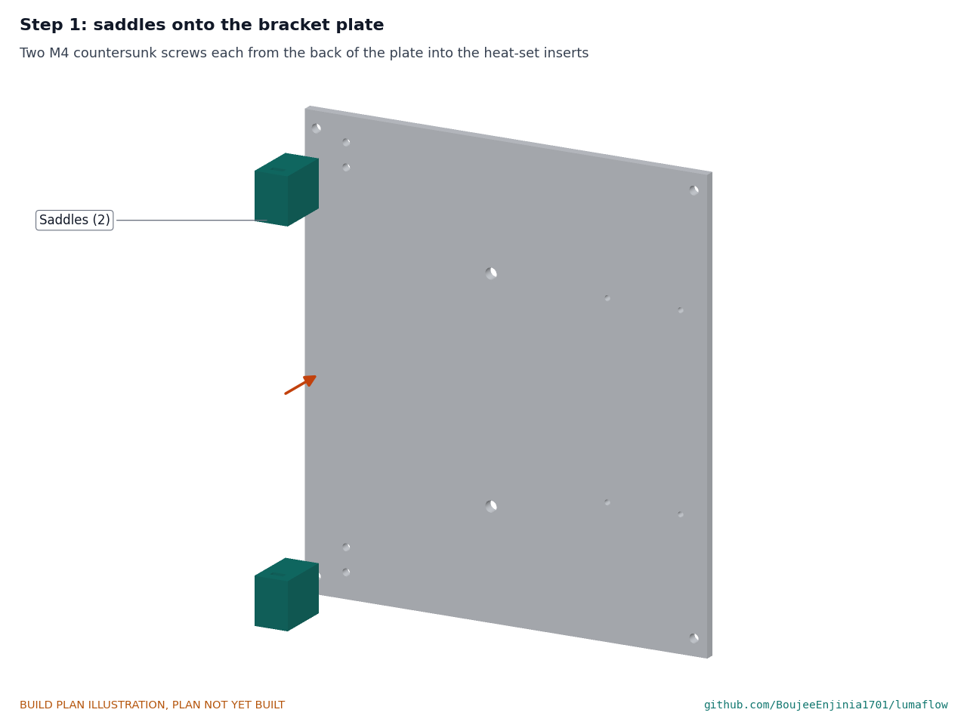
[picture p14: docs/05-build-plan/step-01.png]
Figure 5. Step 1 picture: saddles on the plate


*Figure 5. The back face sits flat on the plate, held by two M4 countersunk screws from behind the plate. The flat back of the flow sensor or valve rests on the front face, and one cable tie through the slot holds it.*

**Check before moving on.** The front face is square to the back face; the inserts are flush.

### 3.3 Pipe clamps and studs (bought)

**What it is and what it is made from.** Two rubber-lined pipe clamps for a 65 mm tube, each with an M8 boss, on an M8 x 20 stainless stud. The band and its rubber together must be 3 mm thick or less, because the tie rods pass 2 mm outside the clamp.

**How it fits the parts next to it.**

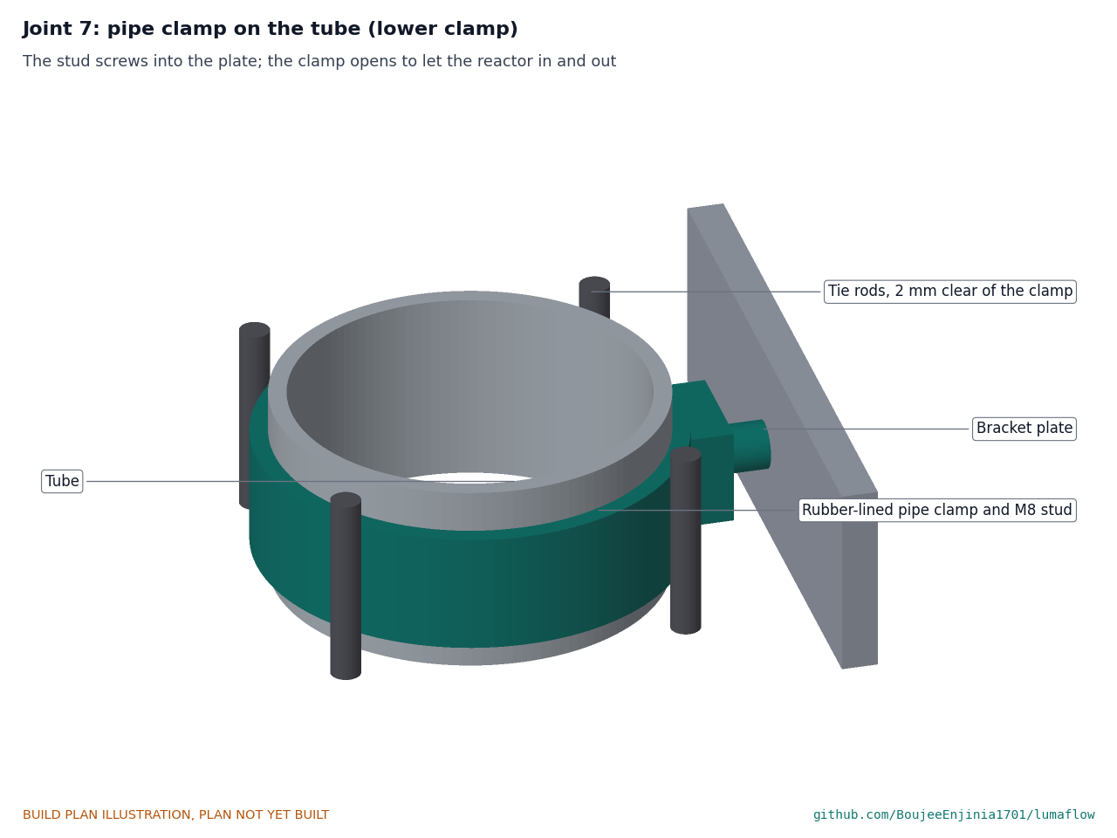
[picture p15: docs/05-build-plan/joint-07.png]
Figure 6. Joint 7: pipe clamp on the tube


*Figure 6. The stud screws into the plate with threadlocker and the clamp onto the stud; the rubber grips the tube. The clamp hinges open to let the reactor in and out.*

**Check before moving on.** Each clamp closes on a 65 mm tube with its screw part way in, and opens fully on its hinge.

### 3.4 Lower end cap

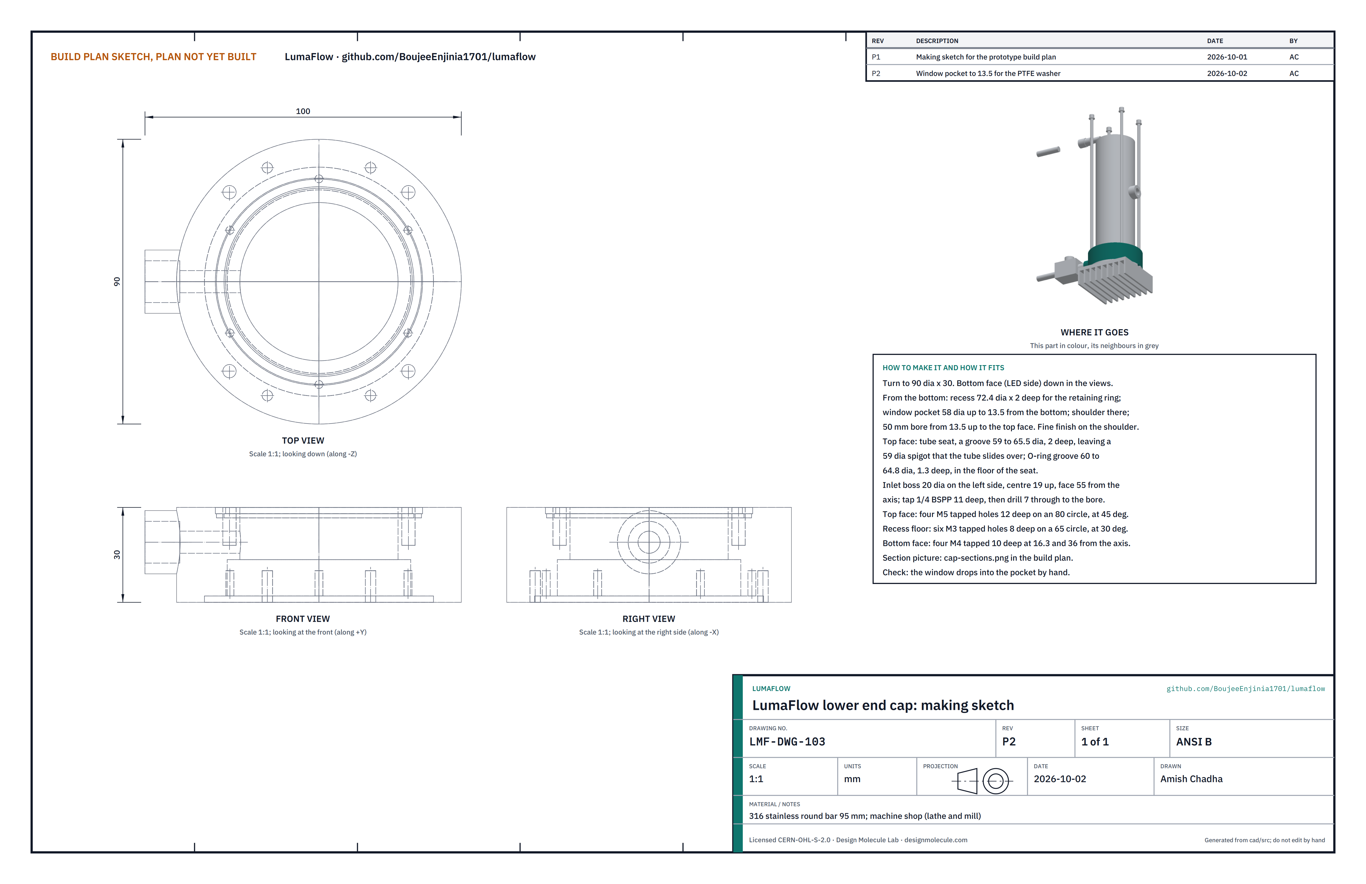
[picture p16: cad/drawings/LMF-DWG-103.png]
Figure 7. Making sketch of the lower end cap


*Figure 7. Lower end cap making sketch (LMF-DWG-103).*

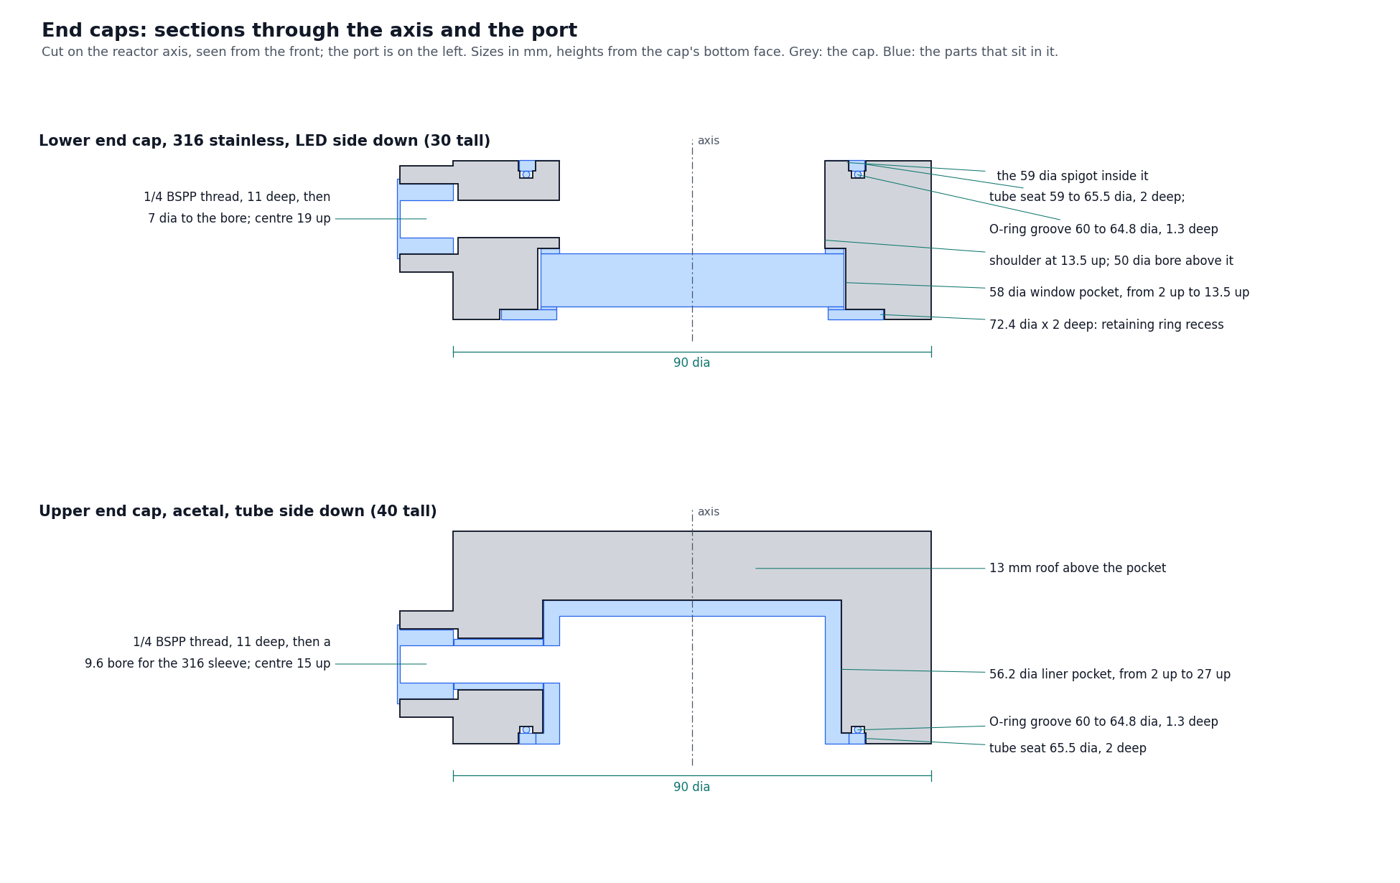
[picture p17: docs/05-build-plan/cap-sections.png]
Figure 8. Sections of both end caps


*Figure 8. Both caps cut through the centre and the port, with the parts that sit in them in blue.*

**What it is and what it is made from.** The stainless block at the bottom of the reactor: it holds the window over the LEDs, carries the water inlet, takes the LED heat into the water and anchors the tie rods. 316 stainless round bar, machined to 90 mm across and 30 mm tall. This is machine-shop work; send them Figures 7 and 8.

**How to make it.** Measure heights from the bottom face (the LED side).

1. Turn the bar to 90 mm across and 30 mm long, faces square.
2. Bottom face: a recess 72.4 across and 2 deep for the retaining ring.
3. Window pocket: 58 across, from the recess up to 13.5 from the bottom face. Leave a fine, flat finish on the shoulder at the top of the pocket; the gasket seals on it.
4. Bore: 50 across, from the shoulder through the top face.
5. Top face: a groove from 59 to 65.5 across and 2 deep for the tube end, leaving a 59 mm spigot inside it; in the floor of that groove, an O-ring groove from 60 to 64.8 across and 1.3 deep.
6. Inlet boss: on the left side, a boss 20 across standing out to 55 from the centre, centred 19 up. Tap it 1/4 BSPP, 11 deep, then drill 7 mm through into the bore.
7. Top face: four M5 tapped holes, 12 deep, on an 80 mm circle, at 45° to the inlet.
8. Floor of the ring recess: six M3 tapped holes, 8 deep, on a 65 mm circle, every 60° starting 30° from the inlet.
9. Bottom face: four M4 tapped holes, 10 deep, 16.3 either side of the centre line and 36 to the front and back.
10. Deburr, clean and passivate.

**How it fits the parts next to it.** The window and its ring fit from below (section 3.5); the LED head screws to the bottom face (section 3.6); the tube sits in the top seat (section 3.8). The stainless bore around the bottom 17.5 mm of the water carries most of the LED heat into the water.

**Check before moving on.** The window drops into its pocket by hand; a 59 mm tube end slides over the spigot.

### 3.5 Window retaining ring, with the window, washer and gasket

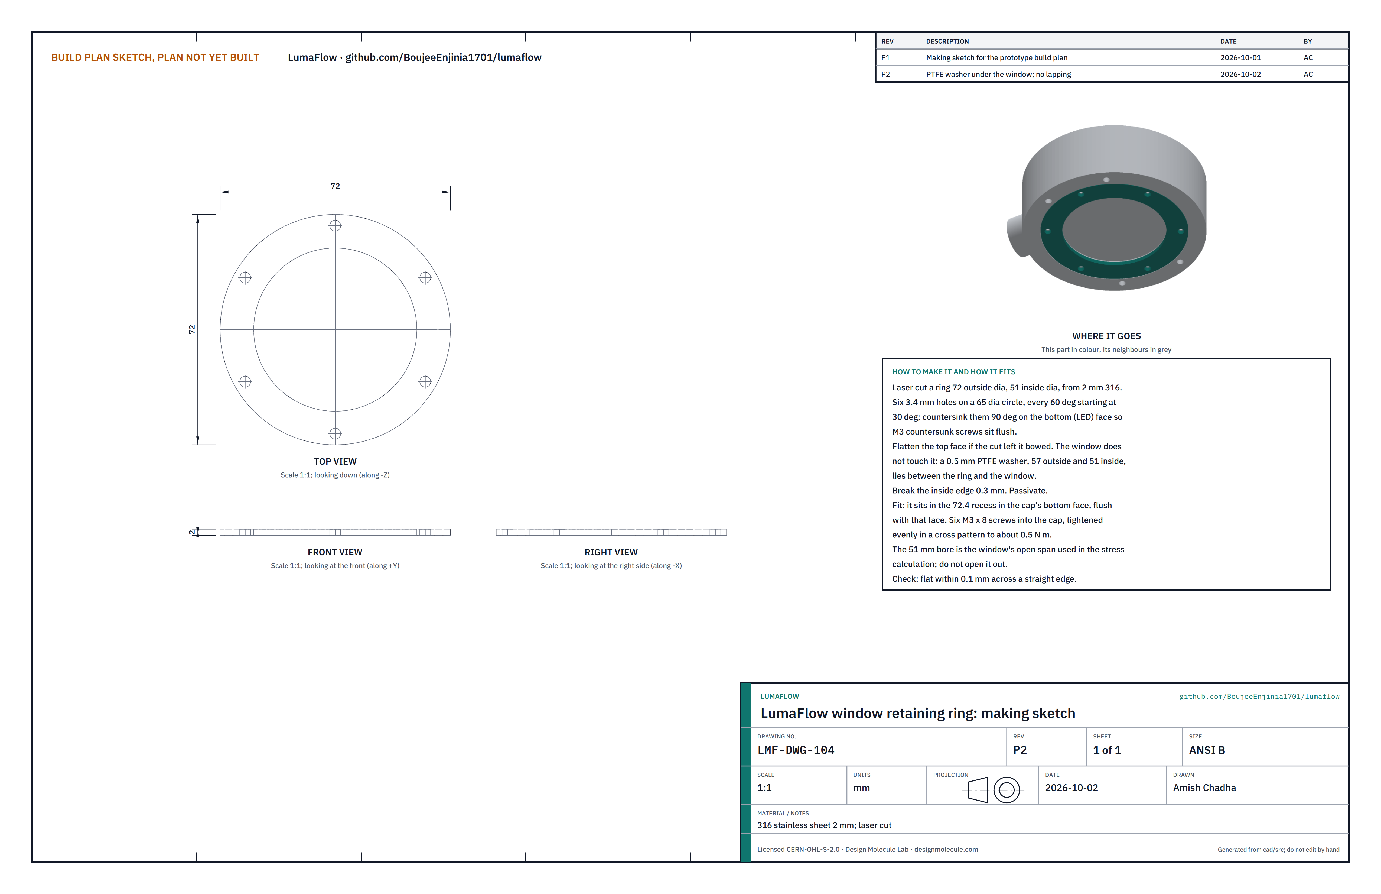
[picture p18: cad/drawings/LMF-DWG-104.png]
Figure 9. Making sketch of the retaining ring


*Figure 9. Retaining ring making sketch (LMF-DWG-104).*

**What it is and what it is made from.** A flat stainless ring that holds the quartz window up against its gasket. 316 stainless sheet 2 mm, laser cut, 72 across outside and 51 across inside. The window (bought) is UV-grade fused silica, 57 across and 10 thick, both faces polished; the gasket (bought or cut) is food-grade EPDM, 57 across outside, 50 inside, 1 thick; the washer (cut) is food-grade PTFE sheet, 57 across outside, 51 inside, 0.5 thick.

**How to make it.**

1. Laser cut the ring with six 3.4 mm holes on a 65 mm circle, every 60° starting at 30°.
2. Countersink the six holes on the bottom face so M3 countersunk screws sit flush.
3. Check the top face is flat and flatten it if the cut left it bowed. The window never touches the metal: the PTFE washer lies between them and spreads the load.
4. Break the inside edge by 0.3 mm and passivate.

**How it fits the parts next to it.**

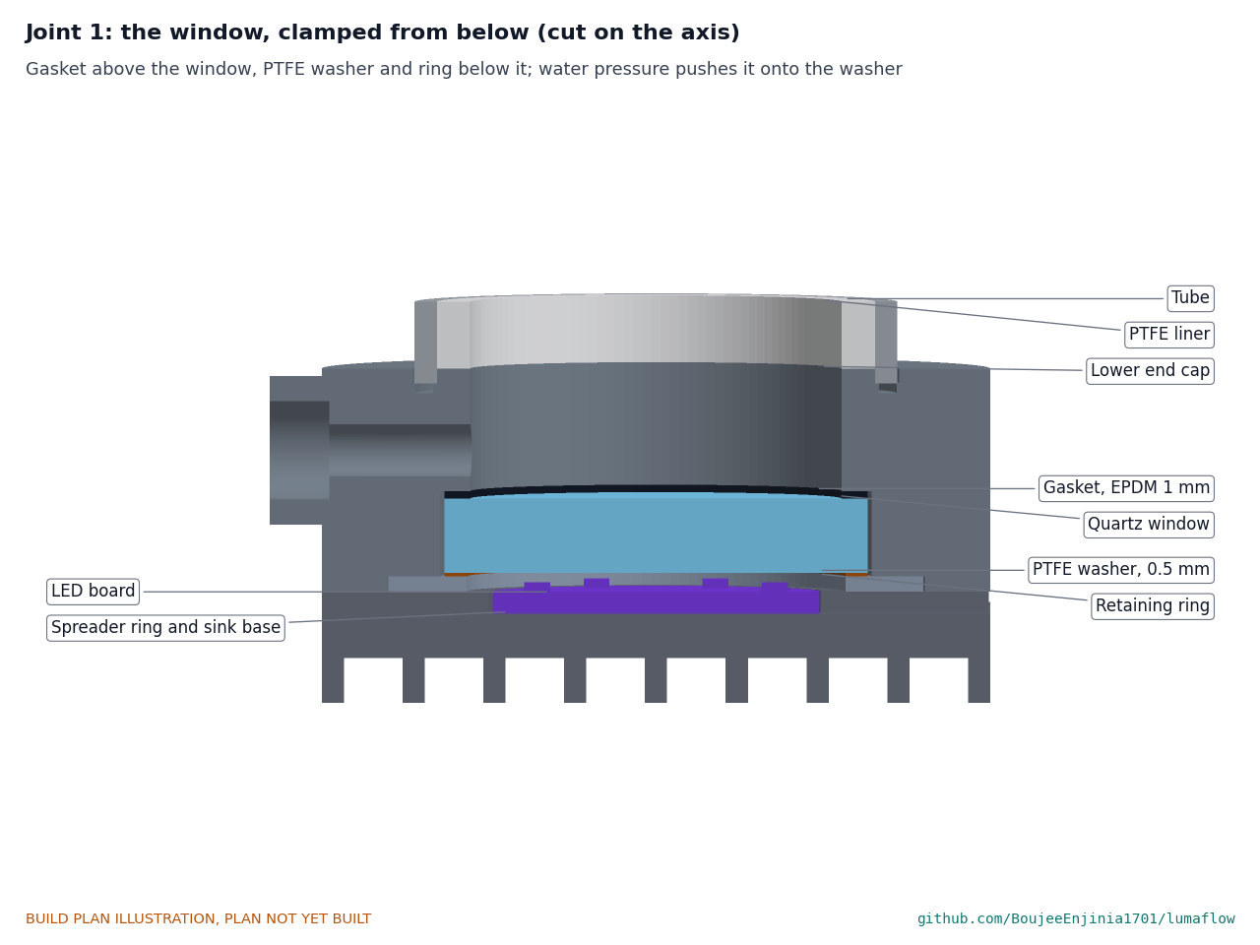
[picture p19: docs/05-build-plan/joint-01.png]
Figure 10. Joint 1: the window, clamped from below


*Figure 10. Cut through the centre: gasket above the window, PTFE washer and ring below it, LEDs 1.3 mm under the window. Water pressure pushes the window down onto the washer and the ring.*

With the cap upside down, the gasket goes into the pocket against the shoulder, then the window, then the washer, then the ring, flush with the cap's bottom face. Six M3 x 8 countersunk screws, tightened evenly in a cross pattern to about 0.5 N·m. The ring's 51 mm opening, and the washer's, is the window's free span used in the stress calculation: do not open either out.

**Check before moving on.** The ring is flat within 0.1 mm across a straight edge; the window sits evenly on the washer with no gap you can see against a light.

### 3.6 Heat sink, spreader ring and LED board

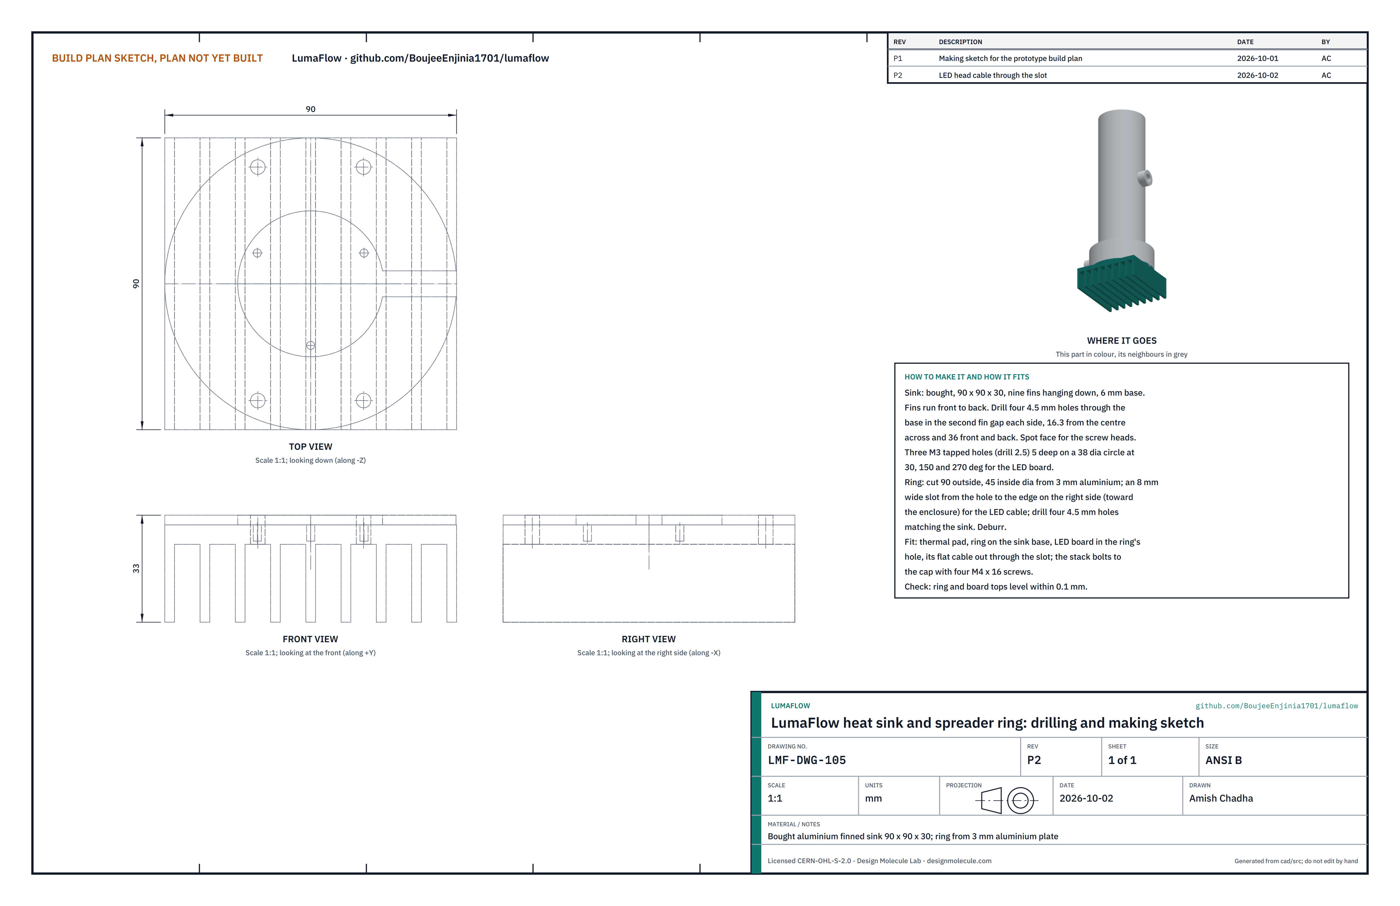
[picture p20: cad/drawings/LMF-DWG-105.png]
Figure 11. Making sketch of the heat sink and spreader ring


*Figure 11. Heat sink and spreader ring sketch (LMF-DWG-105).*

**What it is and what it is made from.** The LED head: a bought finned aluminium heat sink, 90 x 90 x 30 with nine fins hanging down; a flat aluminium spreader ring, 3 thick, 90 across outside and 45 inside, that carries heat from the sink into the stainless cap; and the bought LED board, 44 across, with six 275 nm LEDs and a temperature sensor, which sits in the ring's hole.

**How to make it.**

1. Sink: drill four 4.5 mm holes through the base in the second gap from the middle on each side, 16.3 either side of the centre and 36 to the front and back. Spot face the underside so the screw heads sit square.
2. Sink: three M3 tapped holes, 5 deep, on a 38 mm circle at 30°, 150° and 270°, for the LED board.
3. Ring: cut from 3 mm aluminium plate, 90 across with a 45 hole; cut an 8 mm slot from the hole to the edge on the right side for the LED cable; drill four 4.5 mm holes matching the sink.
4. Deburr everything.
5. Make up the LED head cable: six wires of 0.25 mm², about 95 mm from the edge of the board to a 6-pin plug, laid flat where they pass through the slot and sleeved as one round cable beyond it. Two wires carry the LED string, two the board's thermistor, and two form the interlock loop: they are joined to each other at the board, so the loop is complete only while the plug is in and the cable is whole. Keep the length: it is what stops the head coming off while plugged in.
6. Fit the LED board in the ring's hole on a thermal pad, with three M3 x 10 low-head screws, its cable out through the slot (assembly step 5).

**How it fits the parts next to it.**

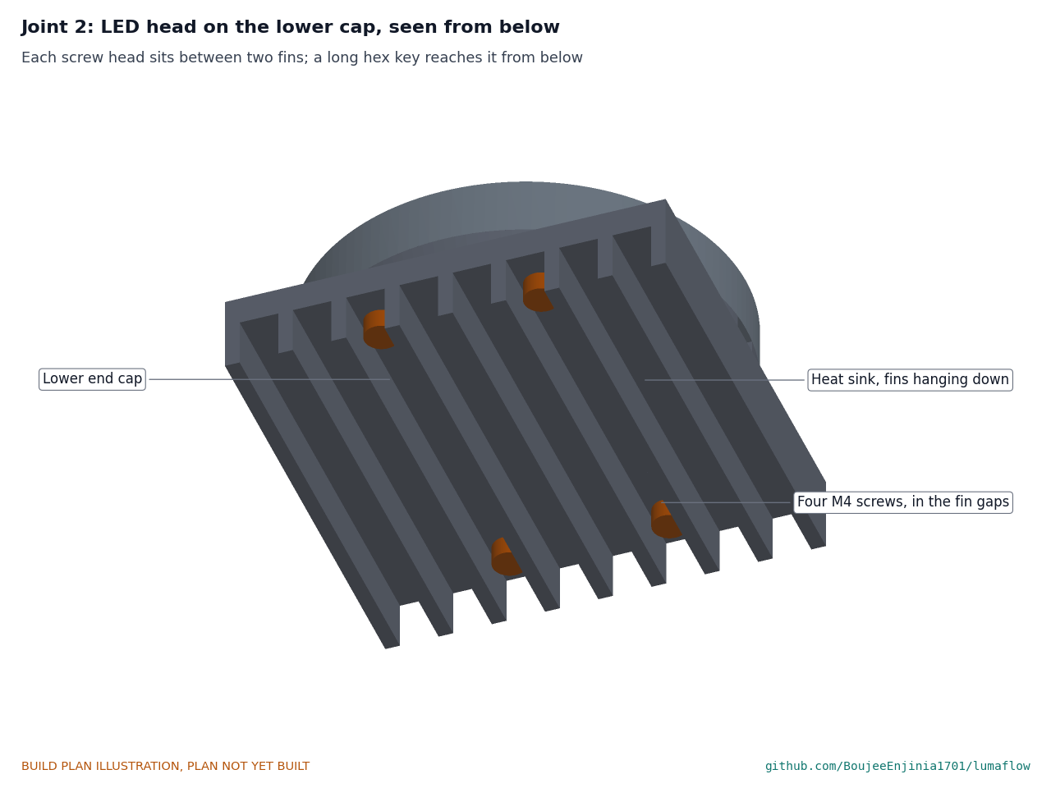
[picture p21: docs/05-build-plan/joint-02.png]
Figure 12. Joint 2: LED head on the lower cap, from below


*Figure 12. Each M4 screw head sits between two fins; a long hex key reaches it from below.*

The ring lies flat on the sink base and on the cap's bottom face, with a thermal pad on each side. Four M4 x 16 socket screws go up from below through the sink and ring into the cap. The LED head can come off without draining or opening the reactor.

**Check before moving on.** The ring and the board are level within 0.1 mm; the screw heads clear the fins.

### 3.7 Tie rod studs (make 4)

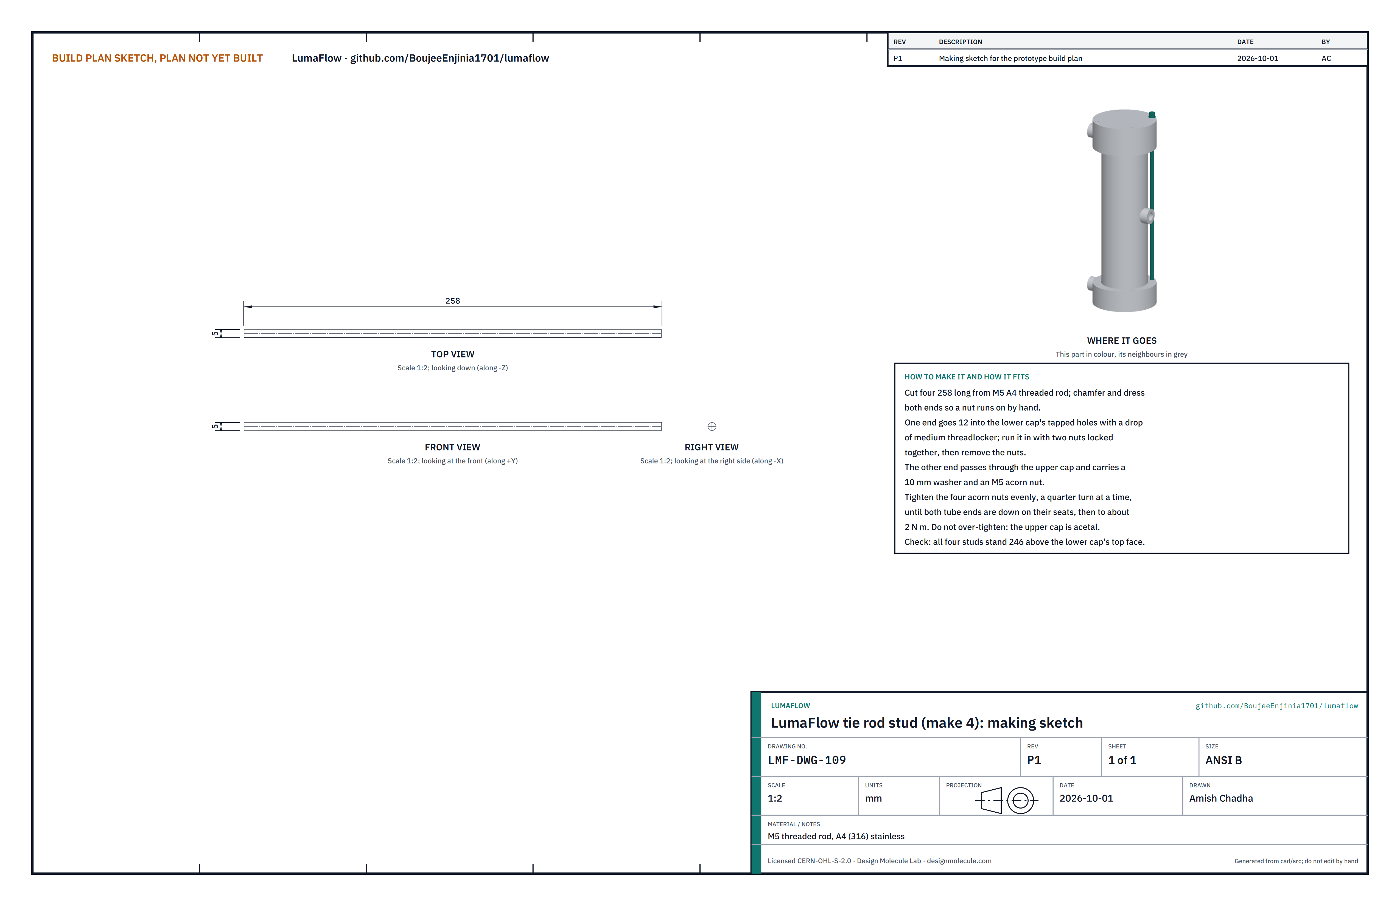
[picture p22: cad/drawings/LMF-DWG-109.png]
Figure 13. Making sketch of the tie rod stud


*Figure 13. Tie rod stud making sketch (LMF-DWG-109).*

**What it is and what it is made from.** The four rods that hold the two end caps together against the water pressure. M5 threaded rod in A4 (316) stainless.

**How to make it.**

1. Cut four lengths of 258 from M5 A4 threaded rod.
2. Chamfer and dress both ends so a nut runs on by hand.

**How it fits the parts next to it.** One end screws 12 mm into the lower cap with a drop of medium threadlocker (run it in with two nuts locked together, then take the nuts off). The other end passes through the upper cap and carries a washer and an acorn nut (Figure 18). The studs pass 2 mm outside the pipe clamps.

**Check before moving on.** All four studs stand 246 above the lower cap's top face, square to it.

### 3.8 Reactor tube with its sensor boss

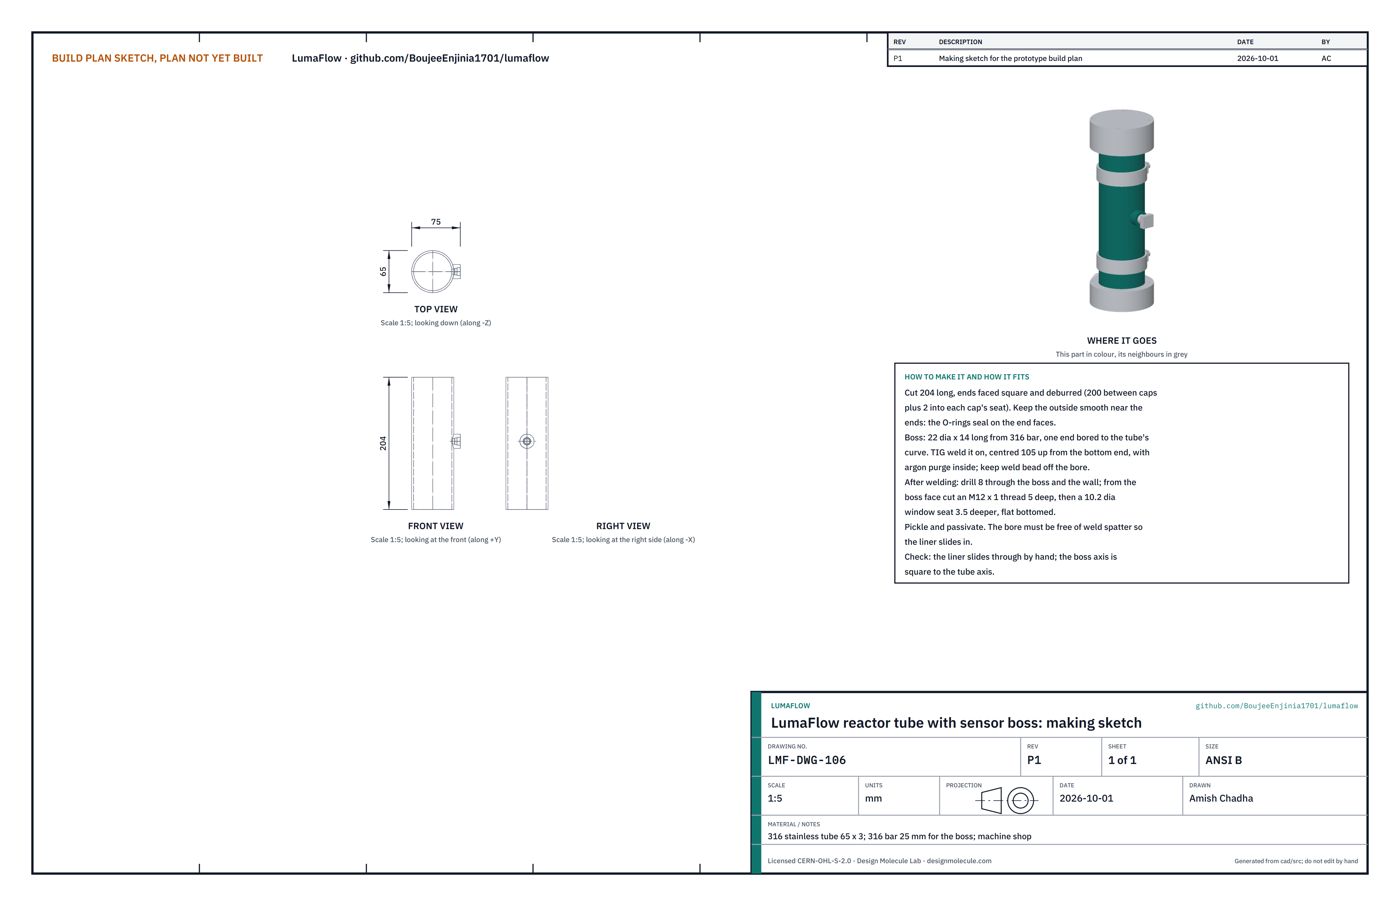
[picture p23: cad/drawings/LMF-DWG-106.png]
Figure 14. Making sketch of the reactor tube


*Figure 14. Reactor tube making sketch (LMF-DWG-106).*

**What it is and what it is made from.** The pressure wall of the reactor, which also blocks all UV-C. 316 stainless tube 65 across and 3 thick, 204 long, with a small boss welded on at mid height for the light sensor. Machine-shop and welding work.

**How to make it.**

1. Cut the tube 204 long and face both ends square and smooth: the O-rings seal on the end faces.
2. Turn a boss 22 across and 14 long from 316 bar, and shape one end to the curve of the tube.
3. TIG weld the boss on, centred 105 up from the bottom end, with argon inside the tube. Keep the weld off the bore.
4. After welding, drill 8 mm through the boss and the tube wall. From the outer face of the boss, cut an M12 x 1 thread 5 deep, then a flat-bottomed seat 10.2 across and 3.5 deeper.
5. Pickle and passivate inside and out. The bore must be clean and free of spatter so the liner slides in.

**How it fits the parts next to it.**

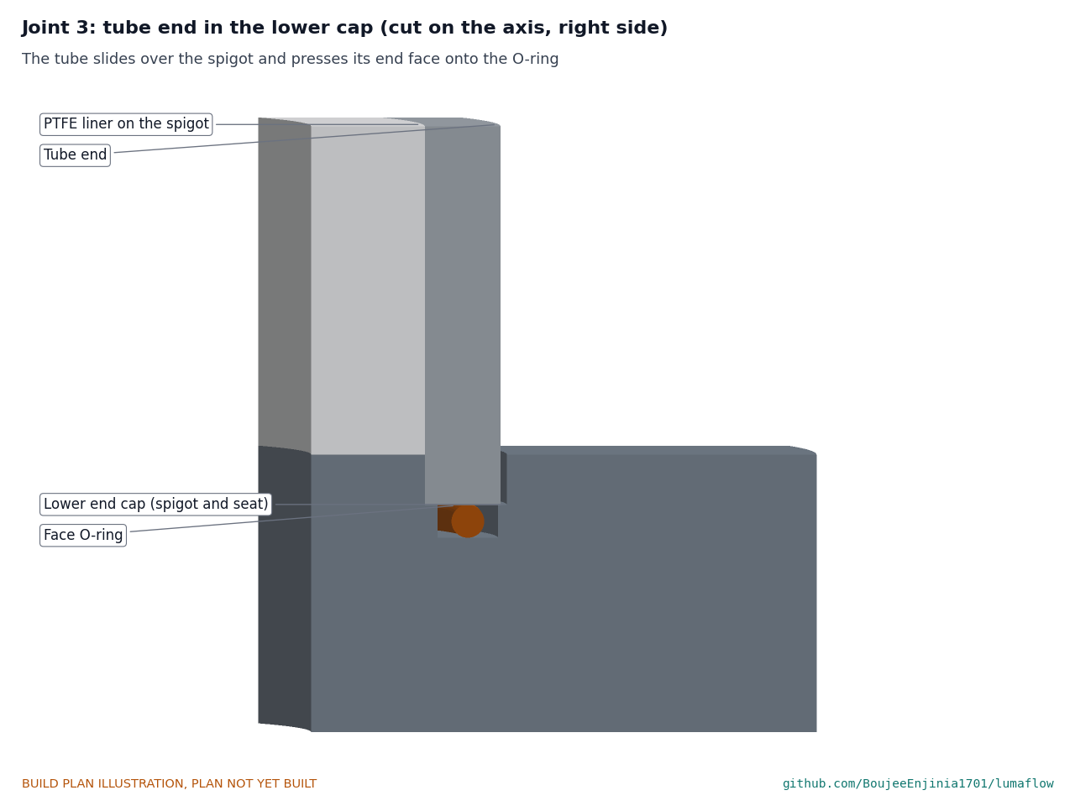
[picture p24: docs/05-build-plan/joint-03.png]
Figure 15. Joint 3: tube end in the lower cap


*Figure 15. Cut through the centre, right side: the tube slides over the spigot and presses its end face onto the O-ring; the liner stands on the spigot.*

Each end sits 2 mm into its cap's seat on a food-grade EPDM O-ring (about 61 mm inside diameter, 1.78 mm section, lightly greased with food-grade silicone grease). The studs press the ends onto the O-rings. The boss faces right, toward the enclosure.

**Check before moving on.** The liner slides through by hand; the boss's axis is square to the tube's axis.

### 3.9 PTFE liner and top disc

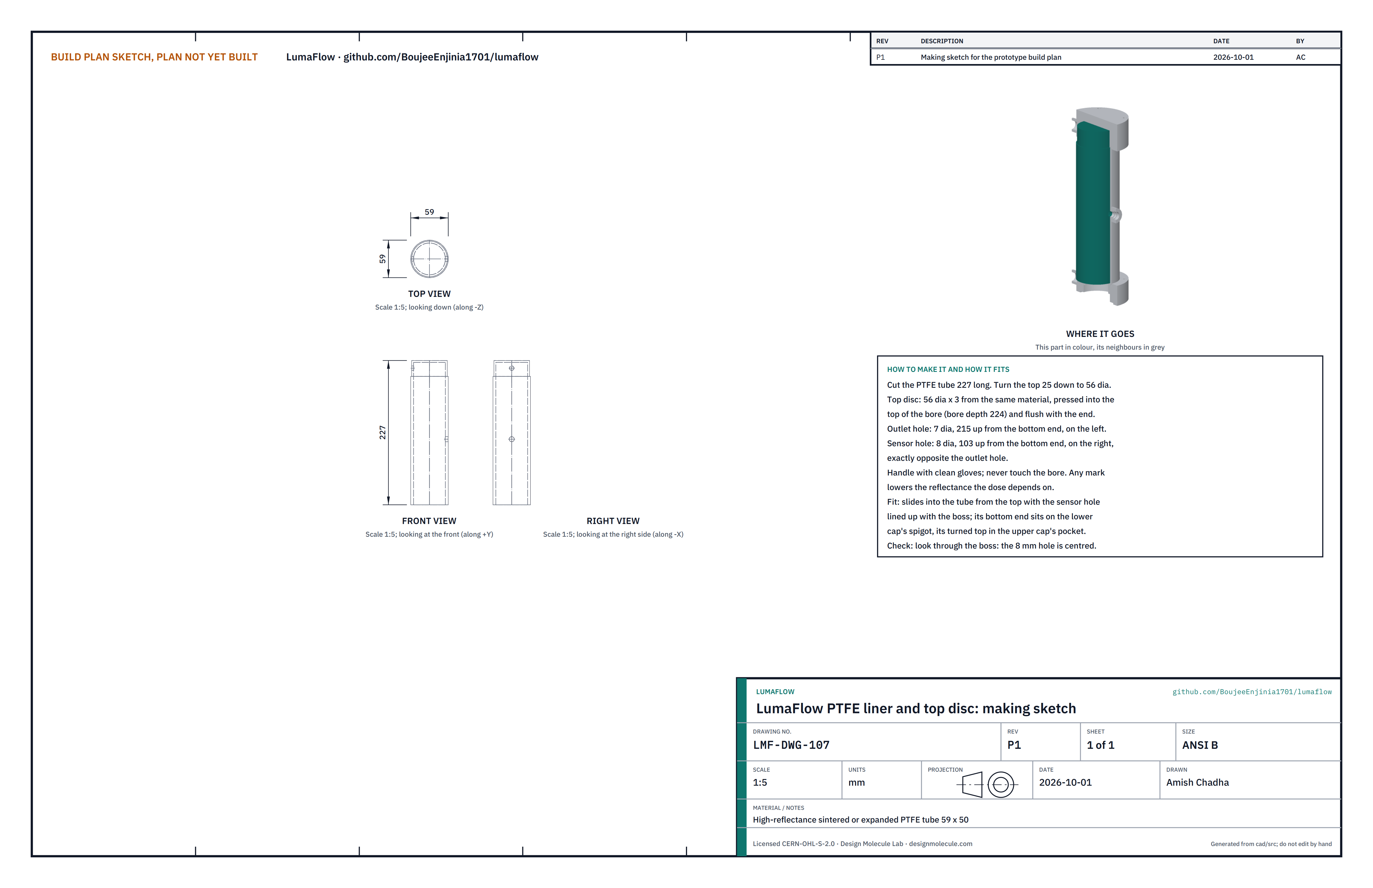
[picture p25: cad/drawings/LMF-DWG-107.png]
Figure 16. Making sketch of the PTFE liner


*Figure 16. PTFE liner making sketch (LMF-DWG-107).*

**What it is and what it is made from.** The white reflective lining of the water channel, closed at the top. High-reflectance sintered or expanded PTFE tube, 59 across outside and 50 inside, and a 56 x 3 disc of the same material. Its whiteness is what makes the dose; never touch the bore, and handle it only with clean gloves.

**How to make it.**

1. Cut the tube 227 long. Turn the top 25 down to 56 across.
2. Press the disc into the top of the bore, flush with the end; the bore is then 224 deep.
3. Drill the outlet hole 7 across, 215 up from the bottom end, on the left.
4. Drill the sensor hole 8 across, 103 up from the bottom end, exactly opposite the outlet hole.

**How it fits the parts next to it.** It slides into the tube from the top with its sensor hole on the boss, stands on the lower cap's spigot, and its turned top goes into the upper cap's pocket (Figures 15 and 18).

**Check before moving on.** Looking in through the boss, the 8 mm hole is centred.

### 3.10 Upper end cap and outlet sleeve

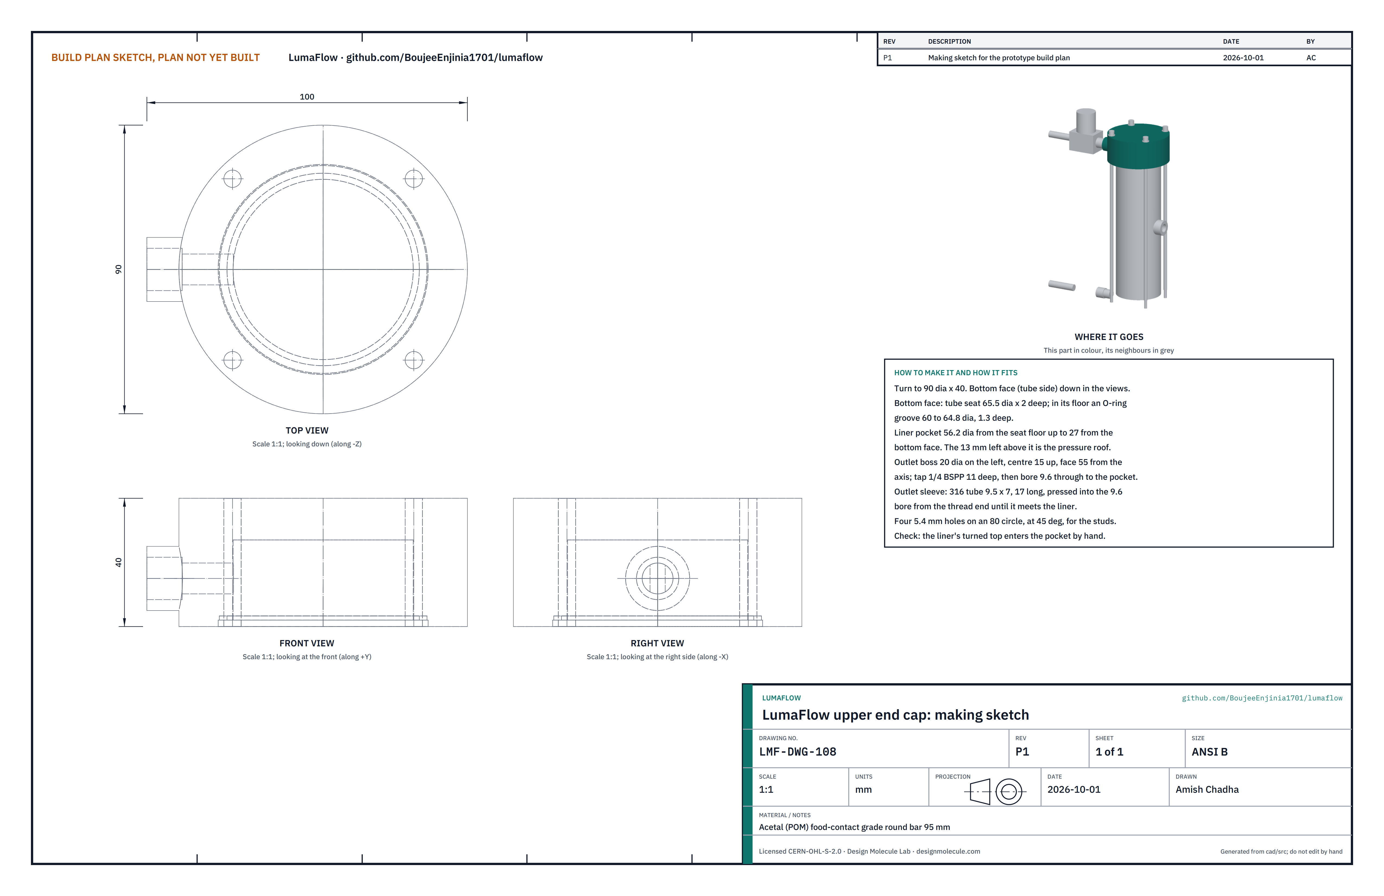
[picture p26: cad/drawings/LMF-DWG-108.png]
Figure 17. Making sketch of the upper end cap


*Figure 17. Upper end cap making sketch (LMF-DWG-108).*

**What it is and what it is made from.** The top of the reactor, with the water outlet. Food-contact acetal round bar, machined to 90 across and 40 tall. It sees no UV-C: the PTFE top disc and liner and a short stainless sleeve in the outlet shield it. The sleeve is 316 tube 9.5 across and 7 inside, 17 long.

**How to make it.** Measure heights from the bottom face (the tube side).

1. Turn to 90 across and 40 tall.
2. Bottom face: a tube seat 65.5 across and 2 deep, with an O-ring groove from 60 to 64.8 across and 1.3 deep in its floor.
3. Liner pocket: 56.2 across, from the seat floor up to 27 from the bottom face. The 13 mm of acetal left above it is the pressure roof; do not go deeper.
4. Outlet boss on the left, 20 across, standing out to 55 from the centre, centred 15 up: tap 1/4 BSPP 11 deep, then bore 9.6 through into the pocket.
5. Four 5.4 mm holes on an 80 mm circle, at 45° to the outlet.
6. Press the stainless sleeve into the 9.6 bore from the thread end until it meets the liner's position (its inner end 28 from the centre).

**How it fits the parts next to it.**

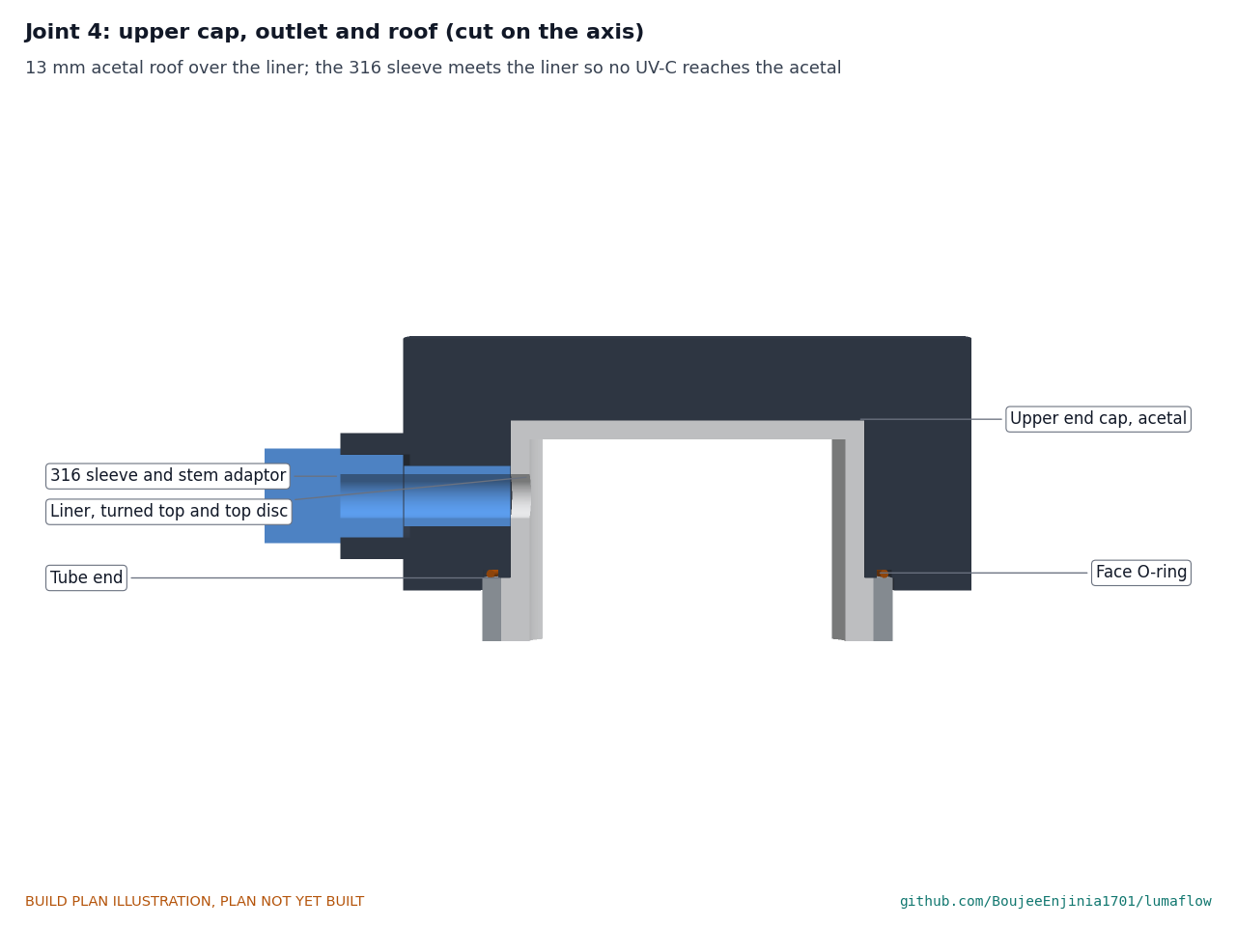
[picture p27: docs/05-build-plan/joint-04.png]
Figure 18. Joint 4: upper cap, outlet and roof


*Figure 18. Cut through the centre: 13 mm roof over the liner; the stainless sleeve meets the liner so no UV-C reaches the acetal; the stem adaptor screws into the thread.*

The tube's top end sits in the seat on the second O-ring; the liner's turned top fills the pocket; the studs pass through the four holes, each with a washer and an acorn nut.

**Check before moving on.** The liner's turned top enters the pocket by hand; the sleeve's bore lines up with the liner's outlet hole.

### 3.11 Light sensor: window, holder and photodiode

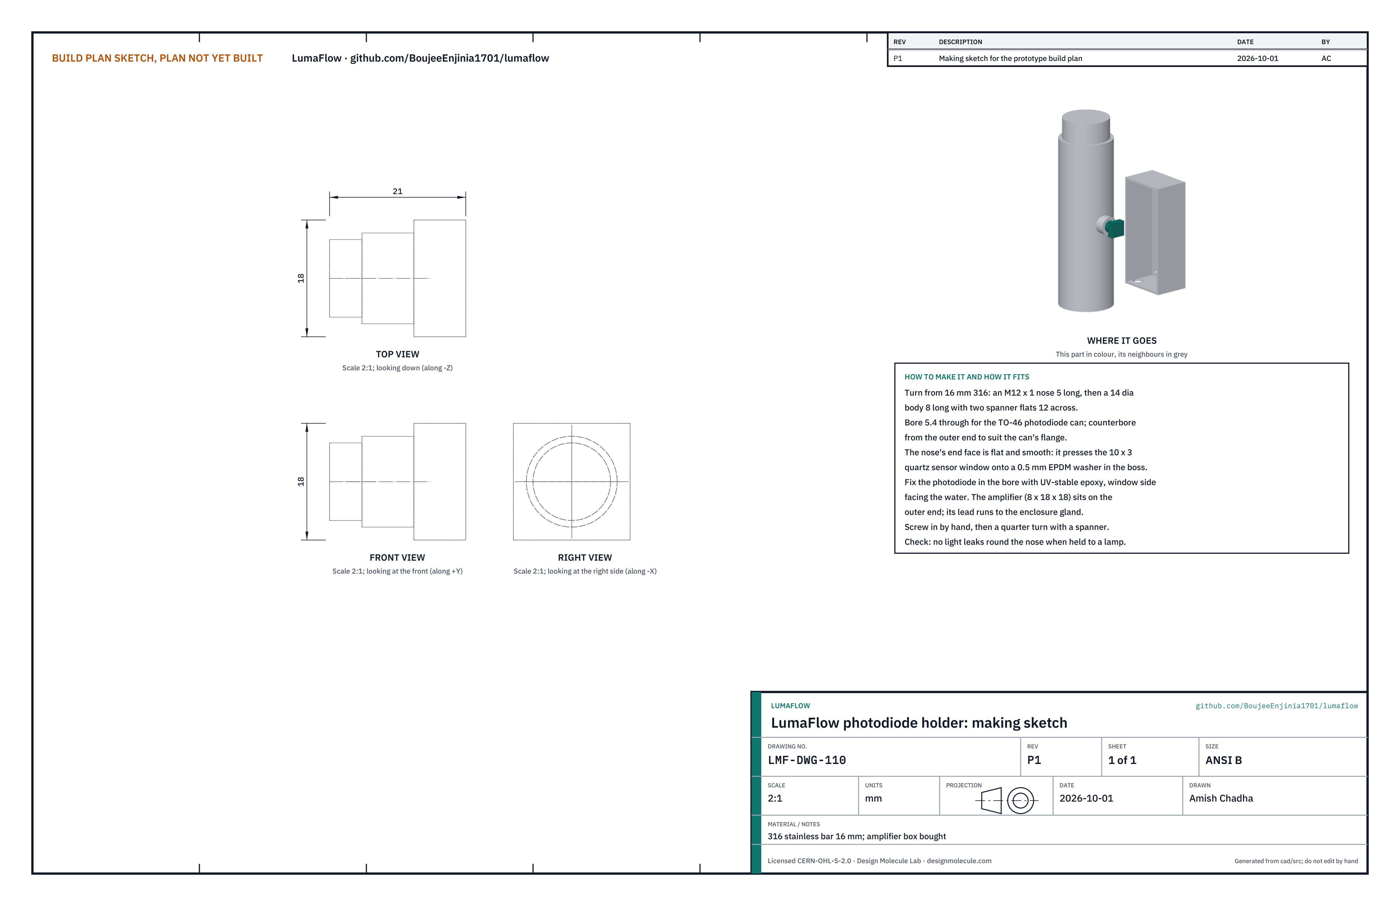
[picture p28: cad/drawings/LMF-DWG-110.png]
Figure 19. Making sketch of the photodiode holder


*Figure 19. Photodiode holder making sketch (LMF-DWG-110).*

**What it is and what it is made from.** The dose sensor that looks into the water through the tube wall. A quartz window 10 across and 3 thick (bought), a 0.5 mm EPDM washer, a holder turned from 316 bar, a bought UV-C photodiode in a small metal can, and a bought amplifier.

**How to make it.**

1. Turn the holder from 16 mm 316 bar: an M12 x 1 threaded nose 5 long, then a body 14 across and 8 long with two spanner flats 12 across.
2. Bore 5.4 through for the photodiode can, with a counterbore at the outer end to suit the can's flange. The nose's end face must be flat and smooth.
3. Fix the photodiode in the bore with UV-stable epoxy, its window toward the nose.
4. Mount the amplifier on the outer end and fit its lead.

**How it fits the parts next to it.**

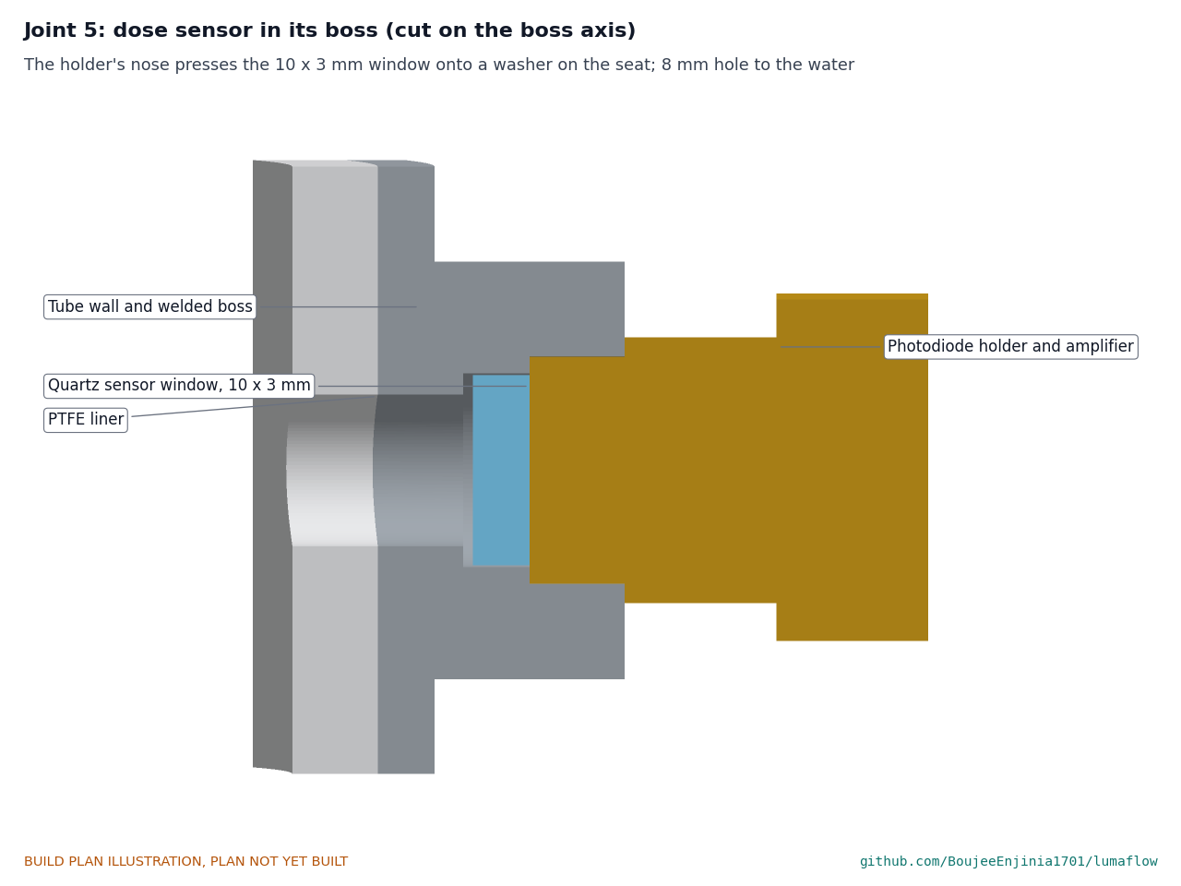
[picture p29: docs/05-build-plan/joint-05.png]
Figure 20. Joint 5: dose sensor in its boss


*Figure 20. Cut through the boss: the holder's nose presses the window onto the washer on the seat; an 8 mm hole leads to the water.*

The washer and window drop into the boss's seat, the holder screws in by hand and then a quarter turn with a spanner. The amplifier's lead runs to the enclosure's gland.

**Check before moving on.** With the holder screwed into a spare M12 x 1 nut and held to a lamp, no light leaks round the nose.

### 3.12 Electronics enclosure

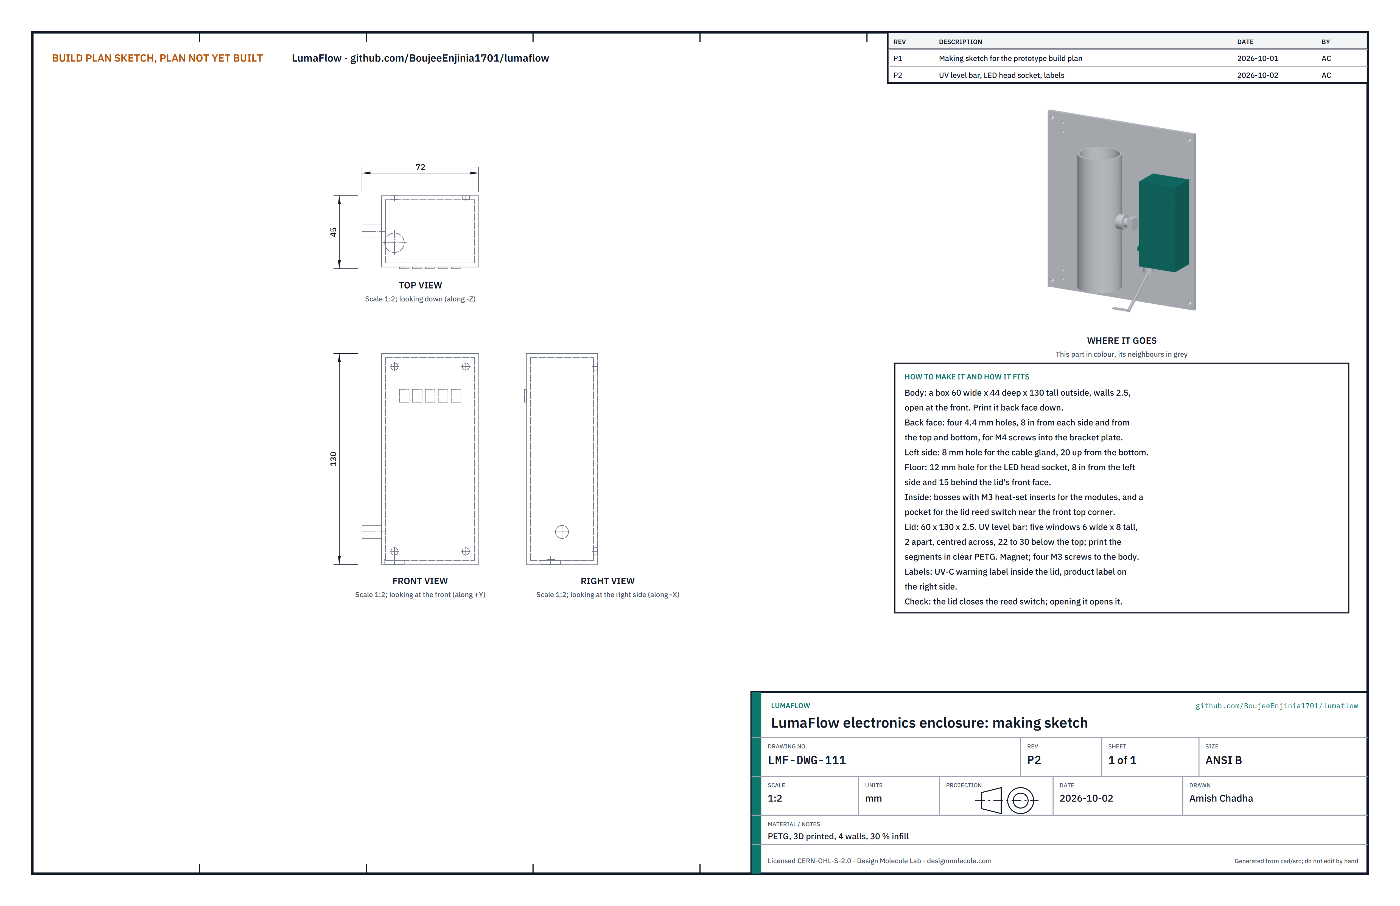
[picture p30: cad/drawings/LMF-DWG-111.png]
Figure 21. Making sketch of the enclosure


*Figure 21. Enclosure making sketch (LMF-DWG-111).*

**What it is and what it is made from.** The box that holds the controller, the LED driver and the valve driver. PETG, printed with 4 walls and 30 % infill: a body open at the front, 60 wide, 44 deep and 130 tall, walls 2.5, and a lid.

**How to make it.**

1. Print the body back face down: four 4.4 mm holes in the back, 8 in from each side and from the top and bottom; an 8 mm hole in the left side, 20 up from the bottom, for the cable gland.
2. In the floor, a 12 mm hole for the LED head's socket, 8 in from the left side and 15 behind the lid's front face.
3. Inside, add bosses with M3 heat-set inserts for the modules and a pocket for the lid reed switch near the front top corner.
4. Print the lid, 60 x 130 x 2.5, with five windows for the UV level bar, each 6 wide and 8 tall, 2 apart, centred across the lid and 22 to 30 below its top edge, and a pocket for the magnet; four M3 screws hold it to the body. Print five segments in clear PETG to fit the windows, standing 1 mm proud of the front; the bar's five LEDs sit behind them.
5. Stick the UV-C warning label inside the lid (Figure 22) and the product label on the right side of the body.

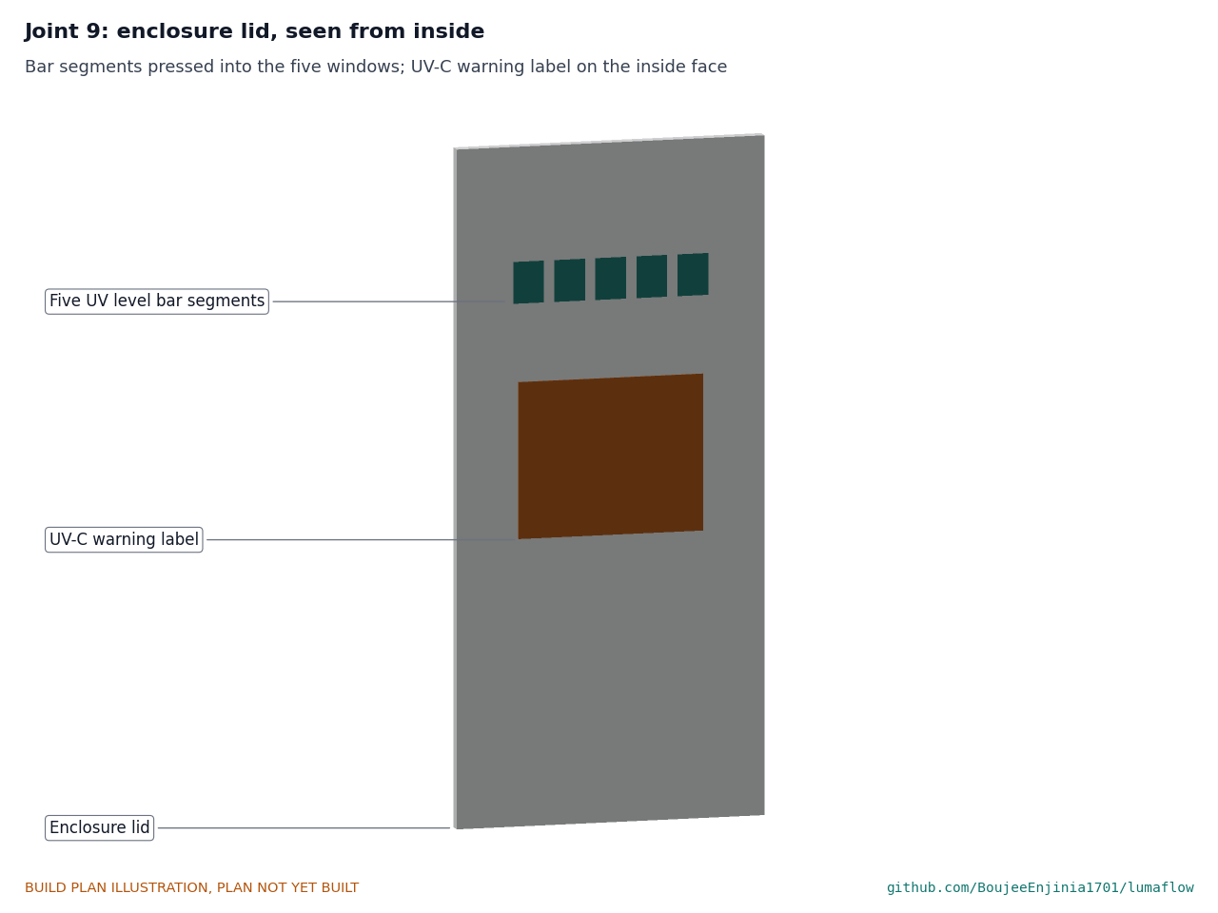
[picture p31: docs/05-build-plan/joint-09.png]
Figure 22. The lid from inside: UV level bar and UV-C label


*Figure 22. The lid seen from inside: the five bar segments in their windows and the UV-C warning label on the inside face.*

**How it fits the parts next to it.** The back sits flat on the bracket plate, held by four M4 x 10 pan-head screws from inside into the plate's tapped holes. The LED head's socket is screwed into the floor hole from inside. Closing the lid brings the magnet to the reed switch, which closes the LED supply.

**Check before moving on.** With a meter on the reed switch, it closes when the lid is on and opens when the lid is lifted 5 mm.

#### 3.12.1 Wiring

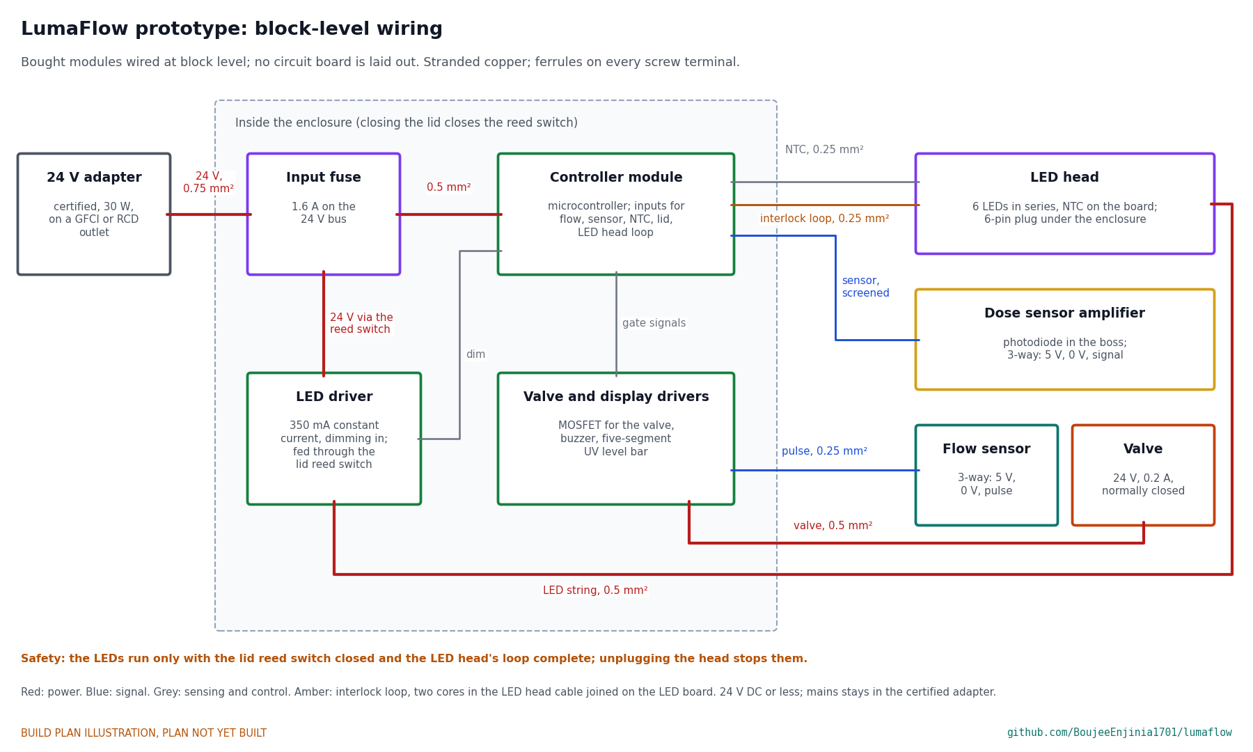
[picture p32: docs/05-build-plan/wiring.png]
Figure 23. Block-level wiring


*Figure 23. Block-level wiring with wire sizes. No circuit board is laid out at this stage; bought modules stand in for the controller board.*

The controller in the bill of materials is module based. Buy modules that meet this specification:

*Table 2. Modules.*

| Module | What to buy |
| --- | --- |
| Controller | Small microcontroller board with a pulse input, an analog input for the sensor amplifier, a thermistor input, a lid switch input, an input for the LED head's interlock loop, outputs for the drivers and five outputs for the UV level bar, run from a 24 V to 5 V converter |
| LED driver | 350 mA constant-current boost driver for a six-LED string of about 37 V, up to 40 V out from the 24 V input, with a dimming input |
| Valve and display drivers | Logic-level MOSFET module with a flyback diode for the 24 V valve; small buzzer; a five-LED bar module behind the lid's five segments |
| LED head plug and socket | 6-pin circular plug and panel socket about 12 mm across, rated for the LED current |
| Fuse | 1.6 A fuse on the 24 V input |

Wire it like this, with stranded copper and a ferrule on every screw terminal:

1. Adapter to the input fuse: 0.75 mm² (18 AWG).
2. Fuse to the controller's 24 V input and to the valve driver: 0.5 mm² (20 AWG).
3. Fuse to the LED driver through the lid reed switch: 0.5 mm².
4. LED driver to the LED head's socket in the enclosure floor: 0.5 mm². The head's own cable (section 3.6) is six wires of 0.25 mm² (24 AWG) from the socket to the board.
5. LED board thermistor to the controller: 0.25 mm², through the same socket.
6. Interlock loop: the two loop pins of the socket to the controller's interlock input, 0.25 mm². The controller keeps the LED driver off unless the loop is complete, so pulling the plug stops the LEDs.
7. Sensor amplifier to the controller: three-core screened cable through the gland, screen grounded at the controller only.
8. Flow sensor to the controller: 0.25 mm², three-way, through the gland.
9. Valve driver to the valve: 0.5 mm², two-way, through the gland.
10. UV level bar module to the controller's five bar outputs, short leads inside the lid.

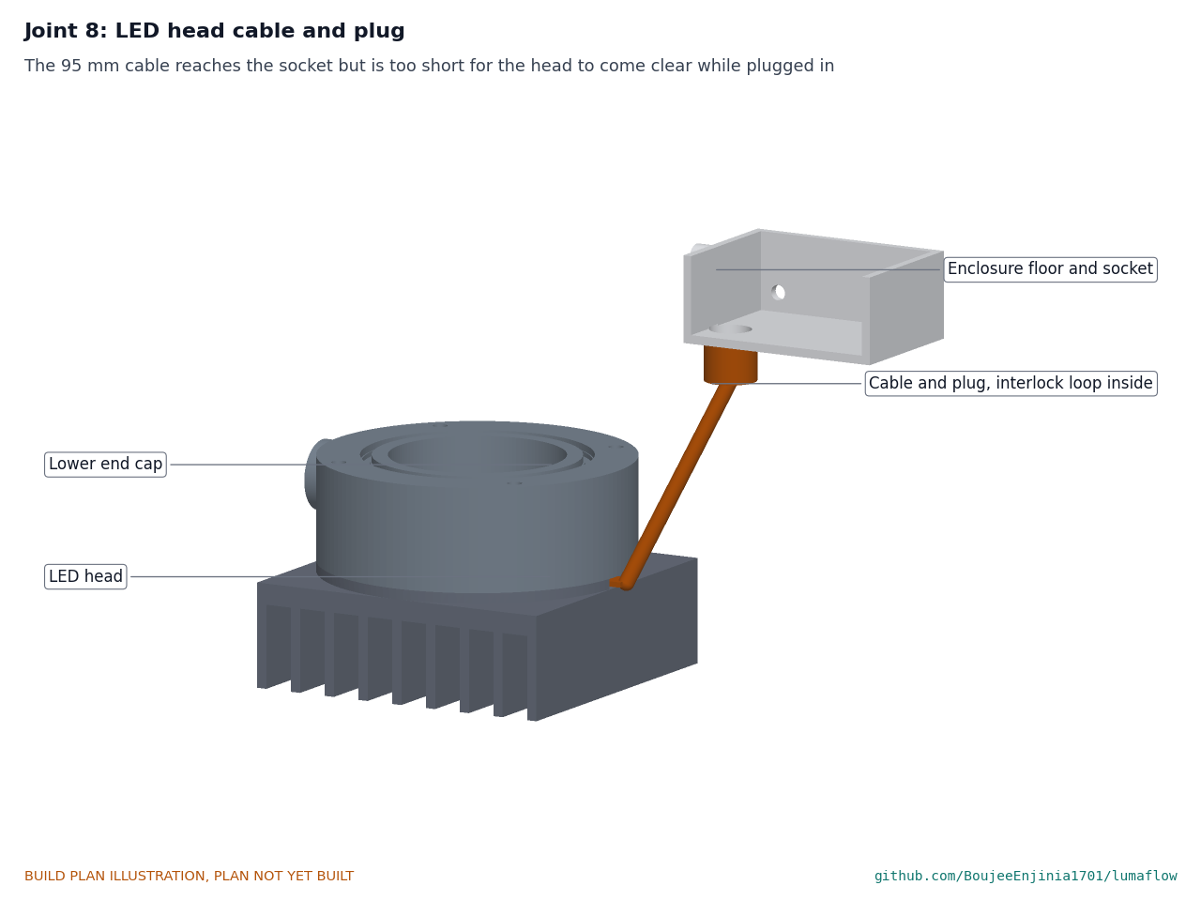
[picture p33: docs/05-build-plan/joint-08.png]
Figure 24. Joint 8: LED head cable and plug


*Figure 24. The LED head's cable runs from the slot in the spreader ring to its plug under the enclosure. It reaches the socket with a little slack, but it is about 39 mm too short for the head to slide clear of the cap while the plug is in.*

**Check before moving on.** Every wire continues end to end; with the adapter unplugged and the lid off, the LED driver's input reads open; the two loop pins of the LED head's plug read a closed circuit, and open as soon as the plug is pulled.

### 3.13 Bought components

Buy to specification, not brand. Line numbers are those of the bill of materials.

- **Quartz window (line 3).** UV-grade fused silica (JGS1 class), 57 across and 10 thick, both faces polished, edges chamfered.
- **LED board (line 4).** Six 275 nm 3535 LEDs, about 60 mW each at 350 mA, on a round 44 mm aluminium-core board with a thermistor and three 3.4 mm holes on a 38 mm circle.
- **Heat sink (line 5).** Aluminium, 90 x 90 x 30, nine fins, gaps of 7.5 mm or more so an M4 socket head fits.
- **Flow sensor (line 8).** Food-grade Hall-effect sensor, 3/8 in push-fit port at each end, flat back, 0.3 to 6 L/min, 15 pulses per second per L/min or more.
- **Photodiode and amplifier (line 9).** SiC UV-C photodiode in a TO-46 can with a transimpedance amplifier.
- **Controller, drivers, LED head plug and socket (line 10).** As Table 2.
- **UV level bar (line 13).** A five-LED bar module behind the five printed segments of the lid.
- **Valve (line 11).** 24 V DC, normally closed, food-grade, 3/8 in push-fit port at each end, flat base, about 0.2 A.
- **Adapter (line 12).** Certified external 24 V DC, 1.25 A adapter, no-load draw 0.1 W or less.
- **Fittings (line 15).** Two stainless push-fit stem adaptors, 1/4 BSPP male to a 3/8 in stem, with bonded sealing washers; 1 m food-grade 3/8 in tube; cold-line tee; 1.2 L/min flow restrictor.

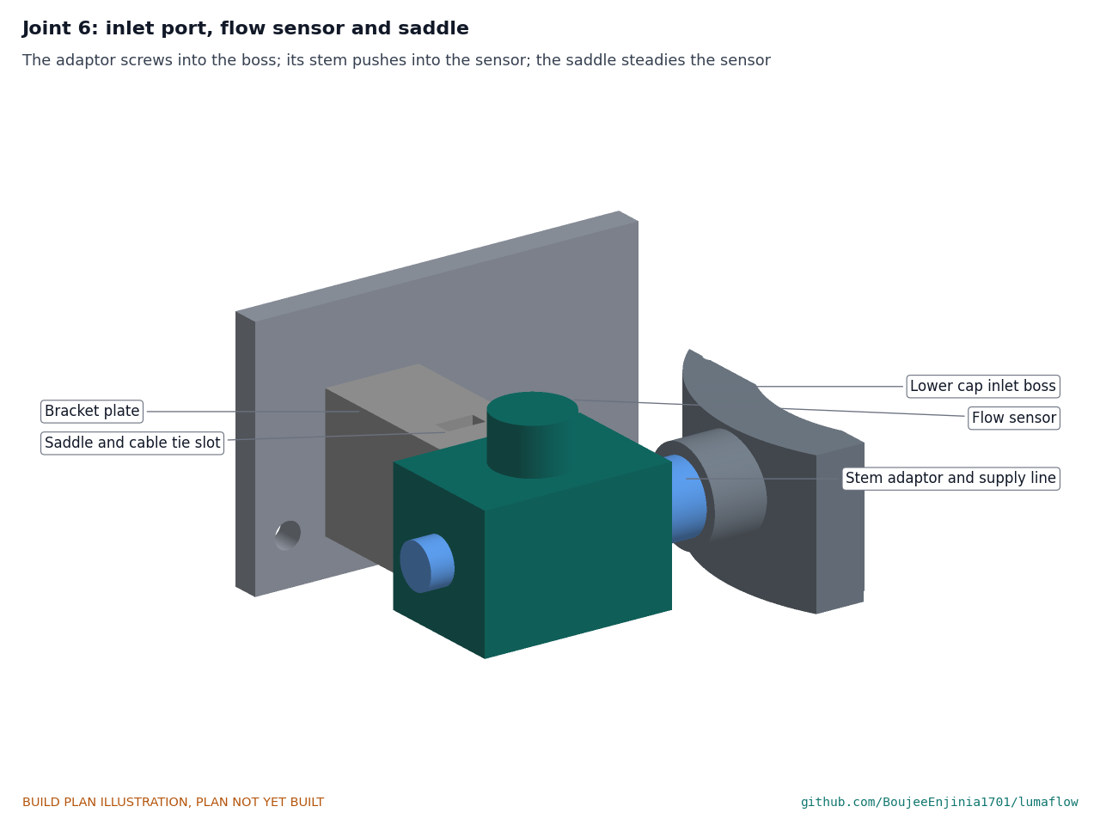
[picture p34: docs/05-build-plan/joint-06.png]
Figure 25. Joint 6: inlet port, flow sensor and saddle


*Figure 25. The stem adaptor screws into the lower cap's boss; its stem pushes into the flow sensor's port; the saddle and a cable tie steady the sensor. The outlet and valve are the same at the top.*

- **Seals and window washer (line 17).** Food-grade EPDM: the window gasket (section 3.5) and two O-rings about 61 inside diameter, 1.78 section. Food-grade PTFE sheet 0.5 mm for the window washer.
- **Labels (line 19).** Two UV-C warning labels with the optical radiation warning sign and the words "UV-C: do not look into the reactor; disconnect power before removing the LED head"; one product label with the name, the 24 V DC rating and "research and educational prototype, not a certified water treatment device".
- **Pipe clamps (line 18).** As section 3.3.
- **Fixings (line 16).** Stainless: four M5 acorn nuts and washers; six M3 x 8 countersunk; four M4 x 16 socket head; three M3 x 10 low head; four M4 x 10 pan head; four M4 x 10 countersunk; two M8 x 20 studs; four wall screws; food-grade silicone grease, thermal pads and paste, medium threadlocker, cable ties.

## 4. Putting it together

In each picture the parts already fitted are grey and the part being fitted is in colour, with an arrow showing the way it goes in.

### Step 1: saddles onto the bracket plate

Step 1

Two M4 countersunk screws each, from the back of the plate into the heat-set inserts.

### Step 2: clamp studs and pipe clamps onto the plate, plate onto the wall

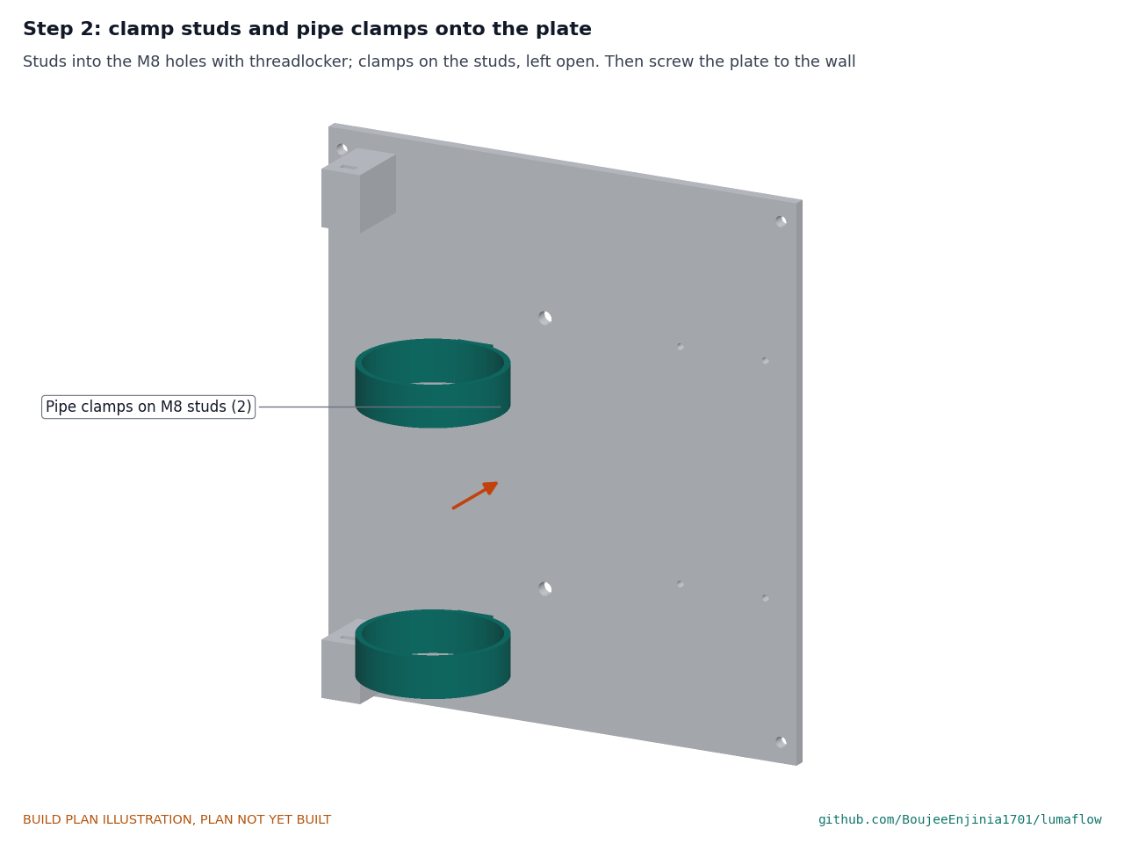
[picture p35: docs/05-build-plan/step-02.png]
Step 2


Studs into the M8 holes with threadlocker, clamps onto the studs, left open. Screw the plate to the cabinet wall (or to a bench board for the first build) on four screws, level, with its bottom edge at least 55 mm above the cabinet floor so the fins will have 25 mm of air under them.

### Step 3: gasket and window into the lower cap, from below

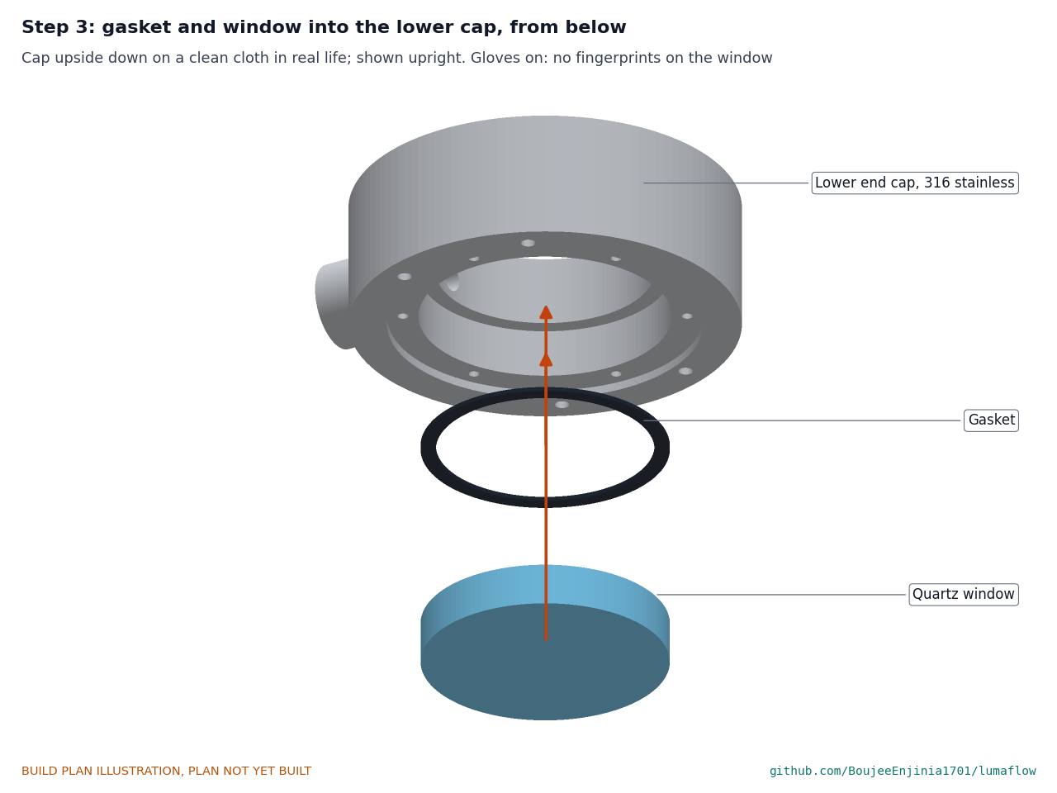
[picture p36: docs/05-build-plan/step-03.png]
Step 3


Stand the cap upside down on a clean cloth (the picture shows it upright, seen from below). Gloves on. The gasket goes against the shoulder, then the window, polished faces clean.

### Step 4: PTFE washer, retaining ring and cap label

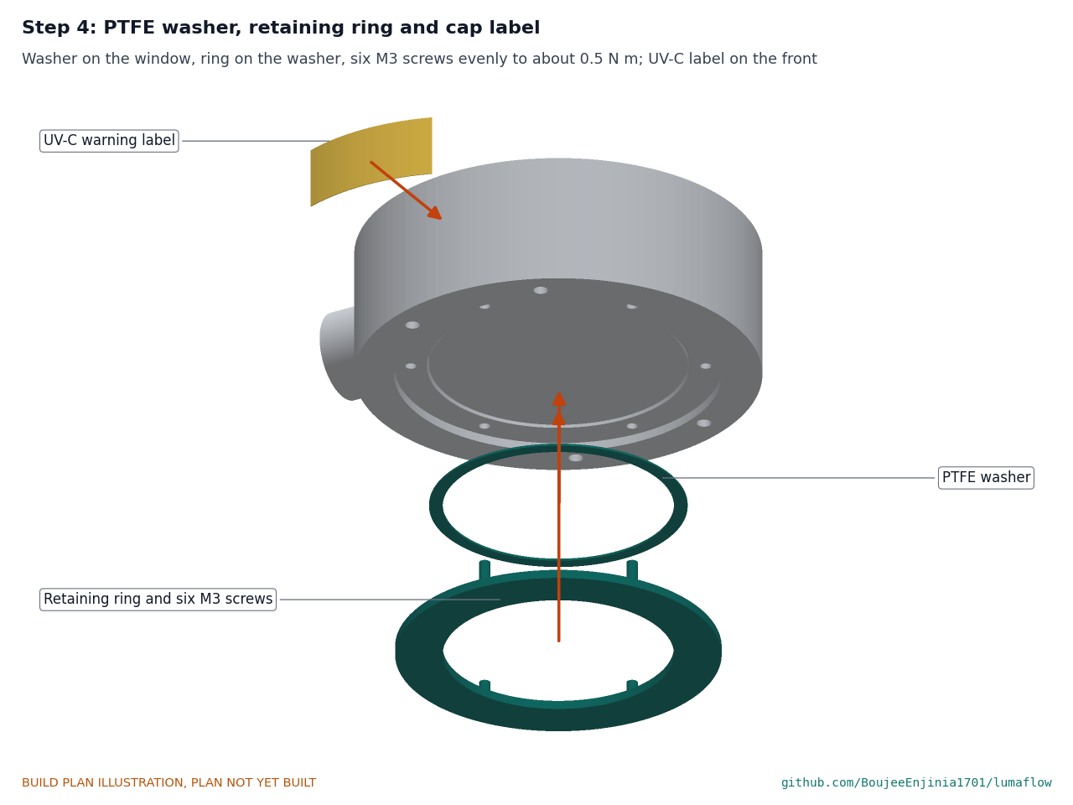
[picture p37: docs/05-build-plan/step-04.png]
Step 4


The PTFE washer on the window, then the ring on the washer. Six M3 countersunk screws, tightened evenly in a cross pattern to about 0.5 N·m. Do not overtighten: quartz cracks under uneven load. Wipe the front of the cap clean and stick on the UV-C warning label, centred on the front of the cap.

### Step 5: LED board and its cable onto the heat sink

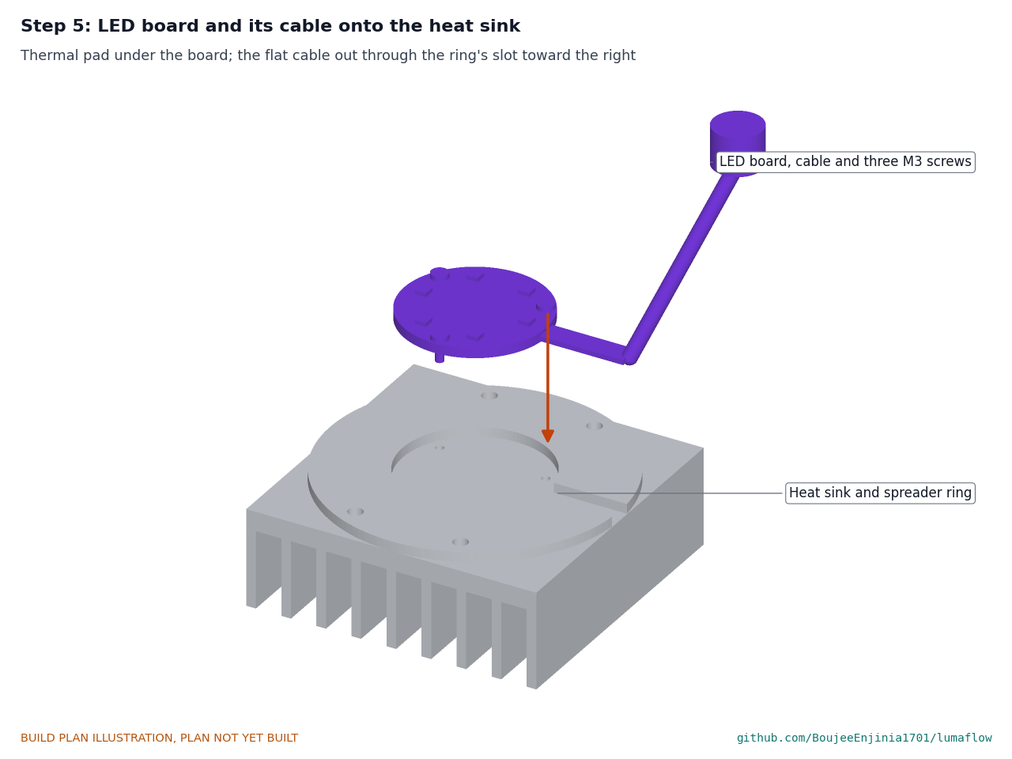
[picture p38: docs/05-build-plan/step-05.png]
Step 5


Thermal pad on the sink, ring on the pad, board in the ring's hole on its own pad, three M3 screws; the flat part of the cable leaves through the slot on the right.

### Step 6: LED head onto the lower cap

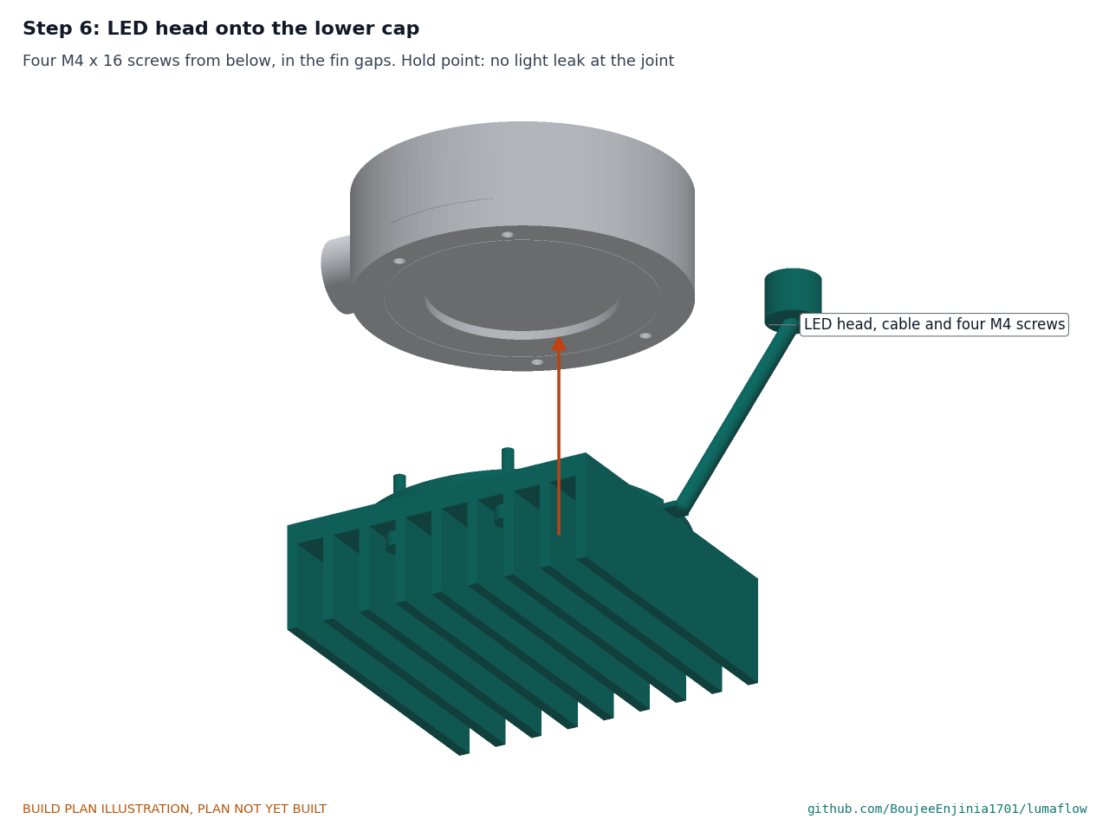
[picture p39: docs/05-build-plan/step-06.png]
Step 6


Thermal pad on the ring, head up against the cap's bottom face, four M4 x 16 screws from below in the fin gaps. **Hold point:** no gap at the joint, and no light from a torch inside the cap leaks out round the head.

### Step 7: studs and lower O-ring into the lower cap

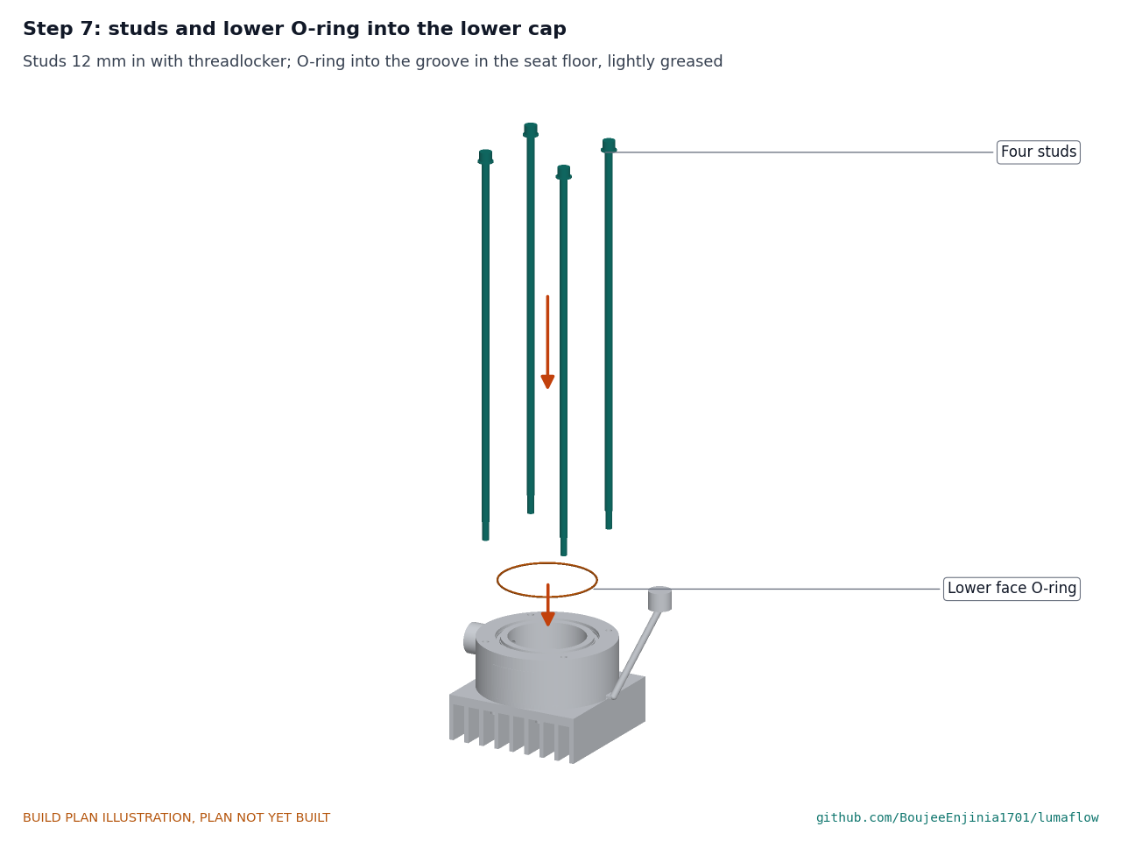
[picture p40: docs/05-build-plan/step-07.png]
Step 7


Studs 12 mm in with threadlocker; let it cure. The O-ring, lightly greased, into the groove in the floor of the tube seat.

### Step 8: tube and liner onto the lower cap

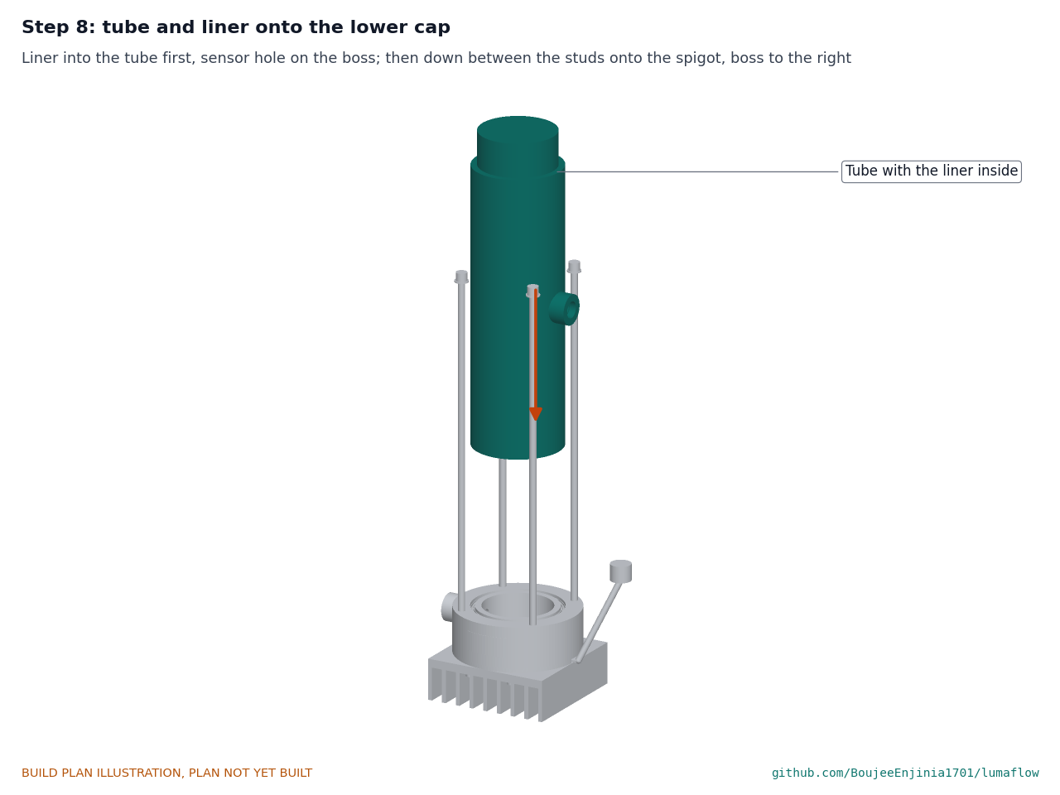
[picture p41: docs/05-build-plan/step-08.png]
Step 8


Slide the liner into the tube first, its sensor hole on the boss. Lower the tube between the studs onto the spigot, boss to the right, until it sits on the O-ring.

### Step 9: upper O-ring and upper cap

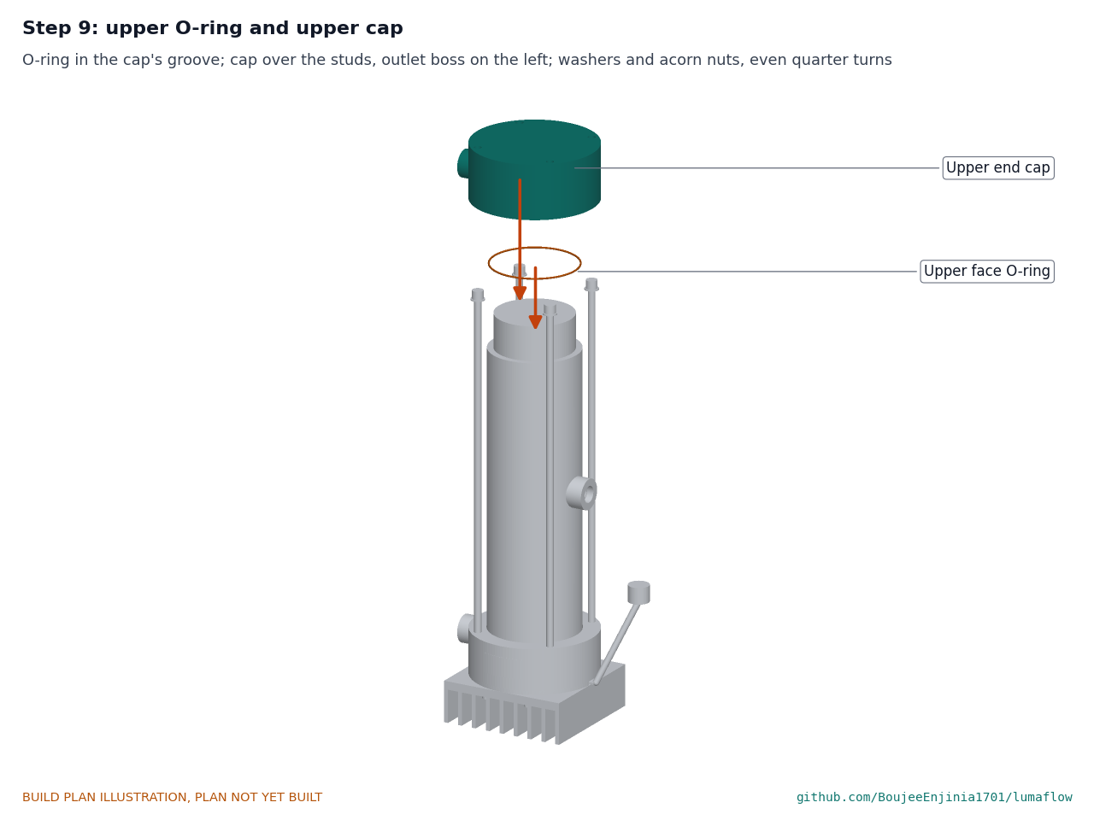
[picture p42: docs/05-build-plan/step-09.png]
Step 9


O-ring into the cap's groove; cap over the studs with its outlet on the left, above the inlet; washers and acorn nuts. Tighten the nuts a quarter turn at a time in a cross pattern until both tube ends are down on their seats, then to about 2 N·m.

### Step 10: outlet sleeve and stem adaptors into the ports

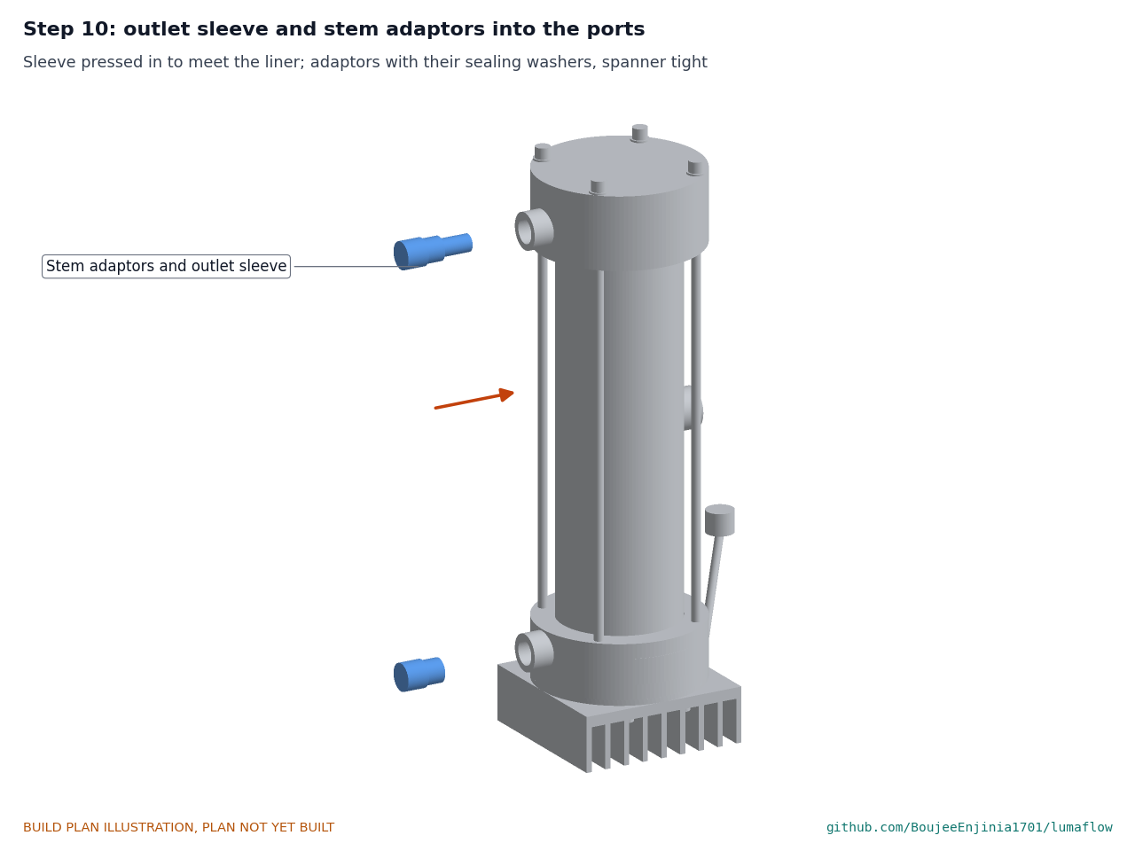
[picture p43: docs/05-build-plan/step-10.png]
Step 10


Check the sleeve is home against the liner; screw each stem adaptor in with its sealing washer, spanner tight.

### Step 11: dose sensor into the boss

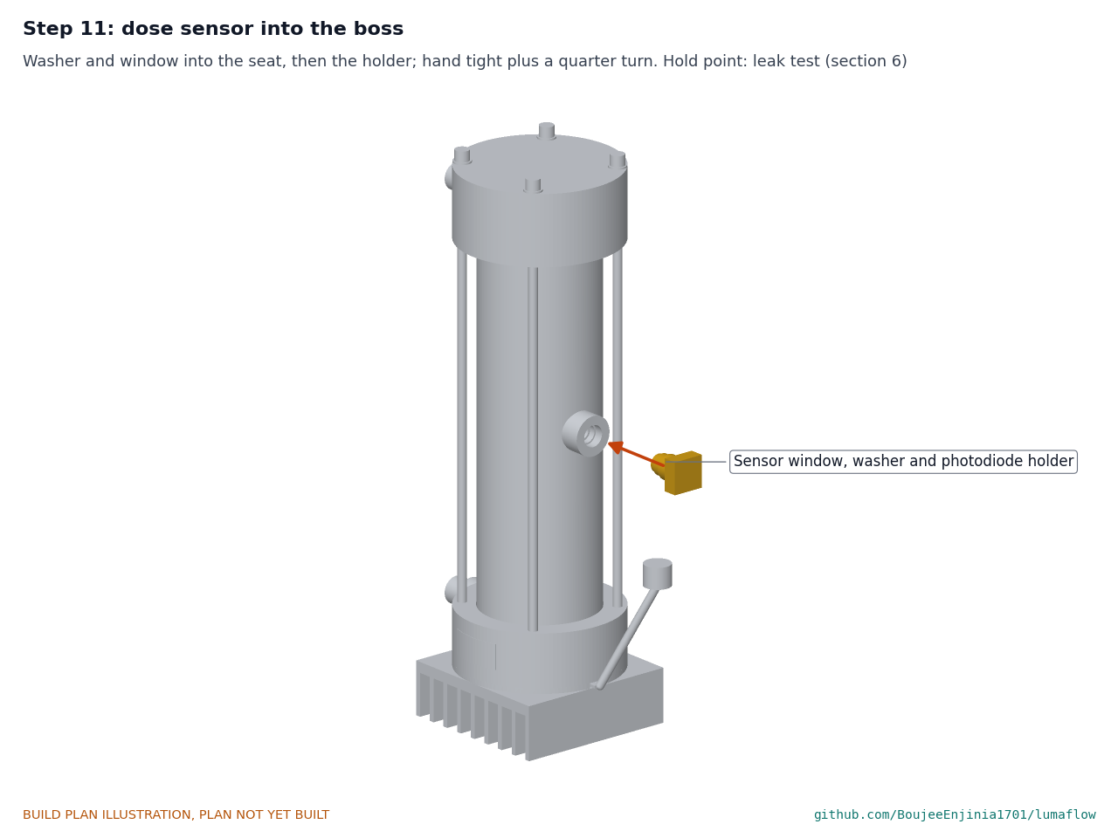
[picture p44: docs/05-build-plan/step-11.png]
Step 11


Washer and window into the seat, then the holder, hand tight plus a quarter turn. **Hold point:** the leak test of safety stop S2 passes before anything electrical is connected.

### Step 12: reactor into the pipe clamps

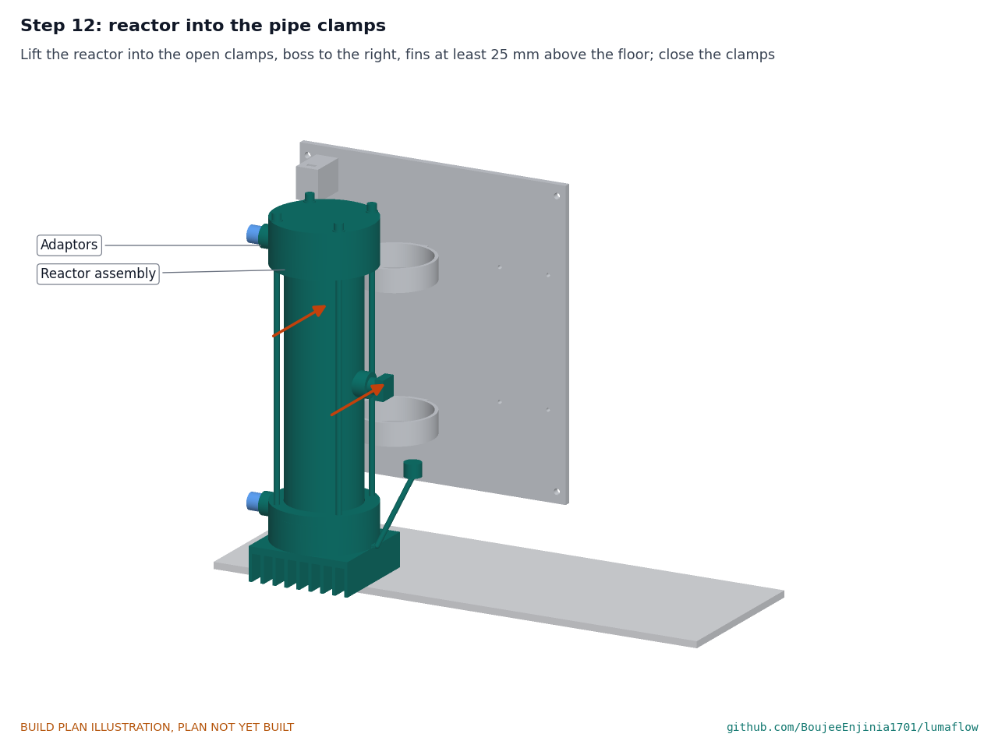
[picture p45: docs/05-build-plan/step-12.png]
Step 12


Lift the reactor into the open clamps, boss to the right, so the fins have at least 25 mm of air under them, and close the clamps until the rubber grips.

### Step 13: enclosure onto the plate

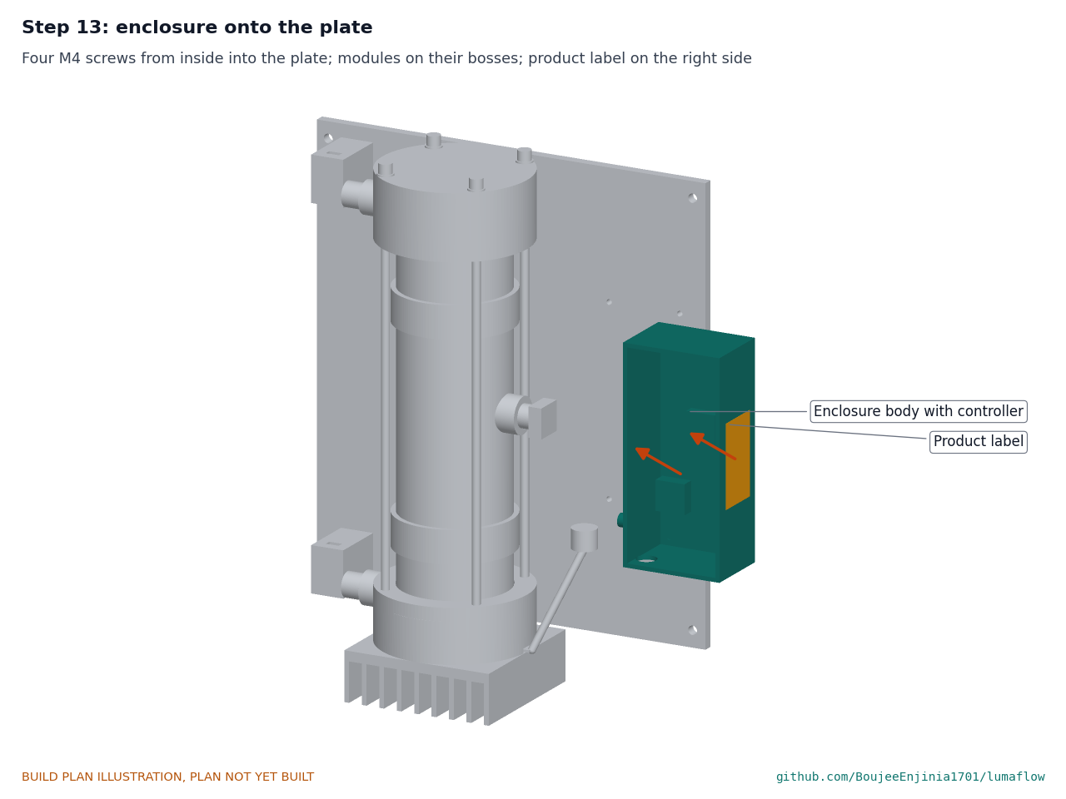
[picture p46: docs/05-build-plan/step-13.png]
Step 13


Controller modules and the LED head socket already fitted, product label on the right side. Four M4 screws from inside the enclosure into the plate.

### Step 14: plug in the LED head, wire up, close the lid

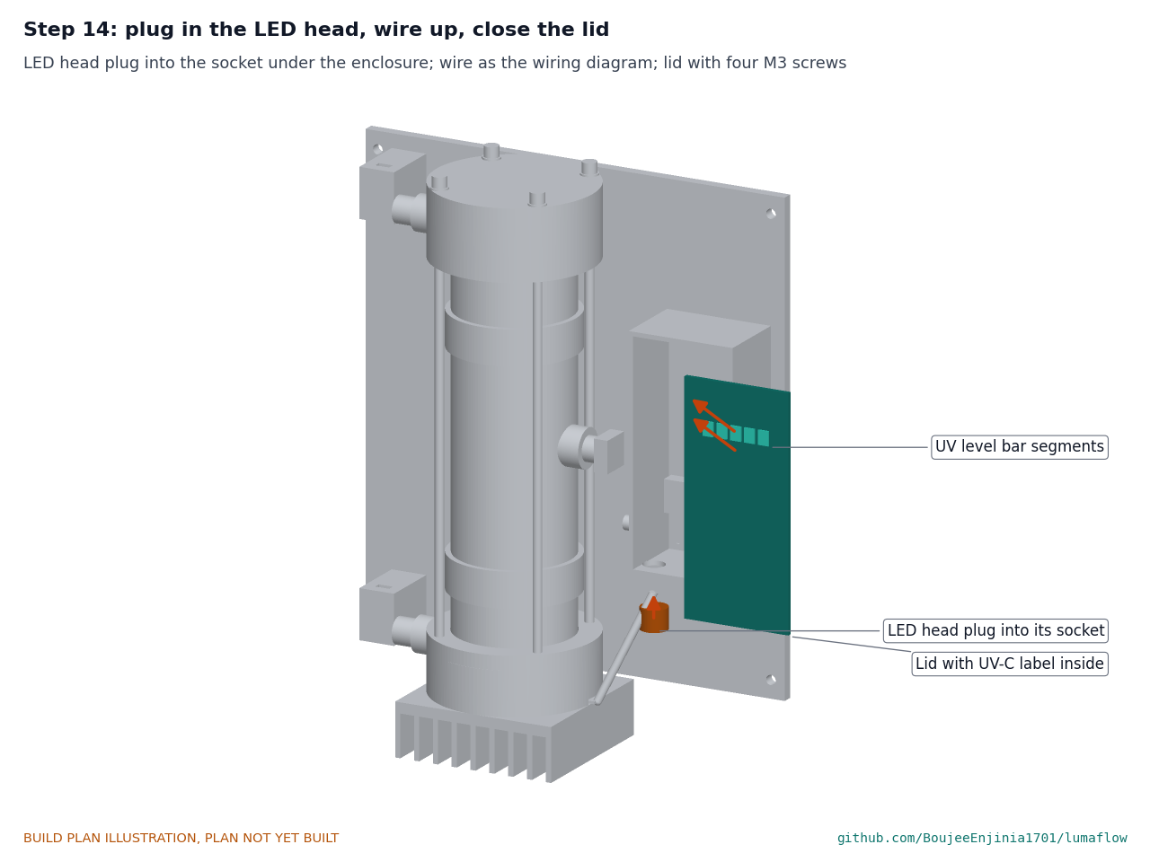
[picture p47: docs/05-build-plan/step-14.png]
Step 14


Push the LED head's plug up into its socket under the enclosure and screw its collar home. Wire as Figure 23, the sensor, flow sensor and valve leads through the gland. Lid on with four M3 screws, the bar segments at the top. **Hold point:** safety stop S3.

### Step 15: flow sensor and valve onto the stems and saddles

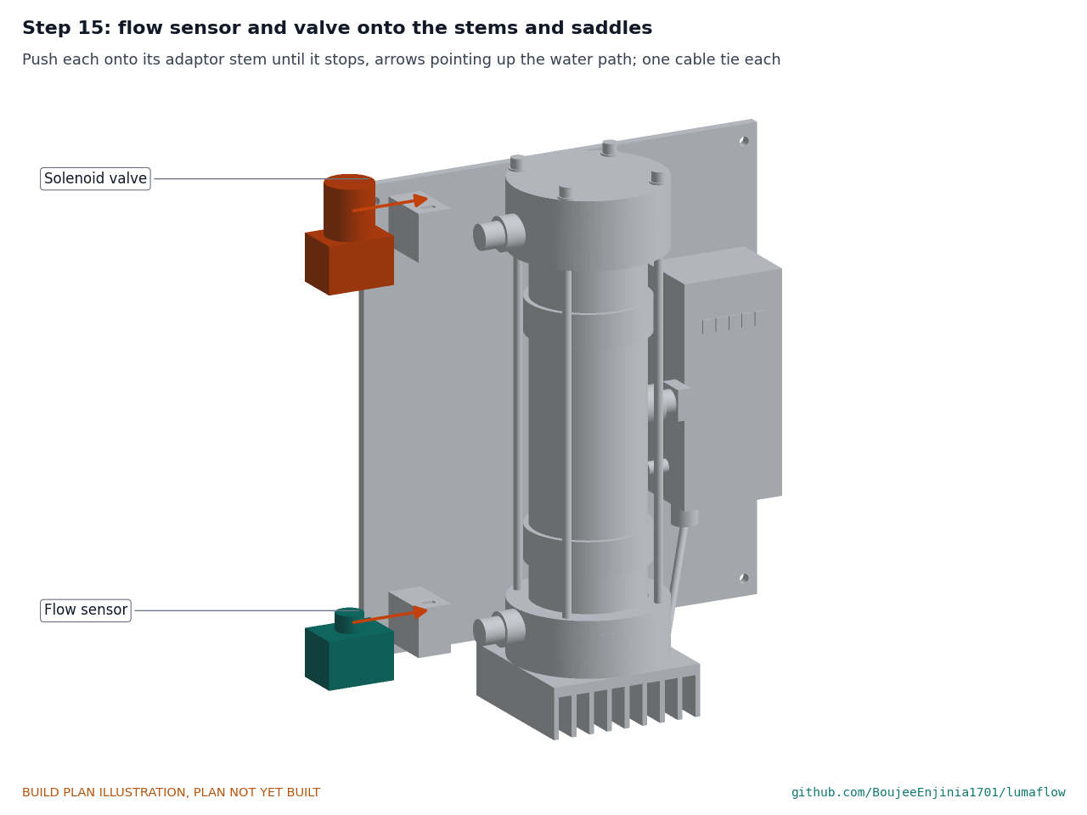
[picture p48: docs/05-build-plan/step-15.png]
Step 15


Push each onto its adaptor's stem until it stops, flow arrows pointing up the water path (into the reactor at the bottom, out at the top). One cable tie through each saddle.

### Step 16: water lines and the 24 V adapter

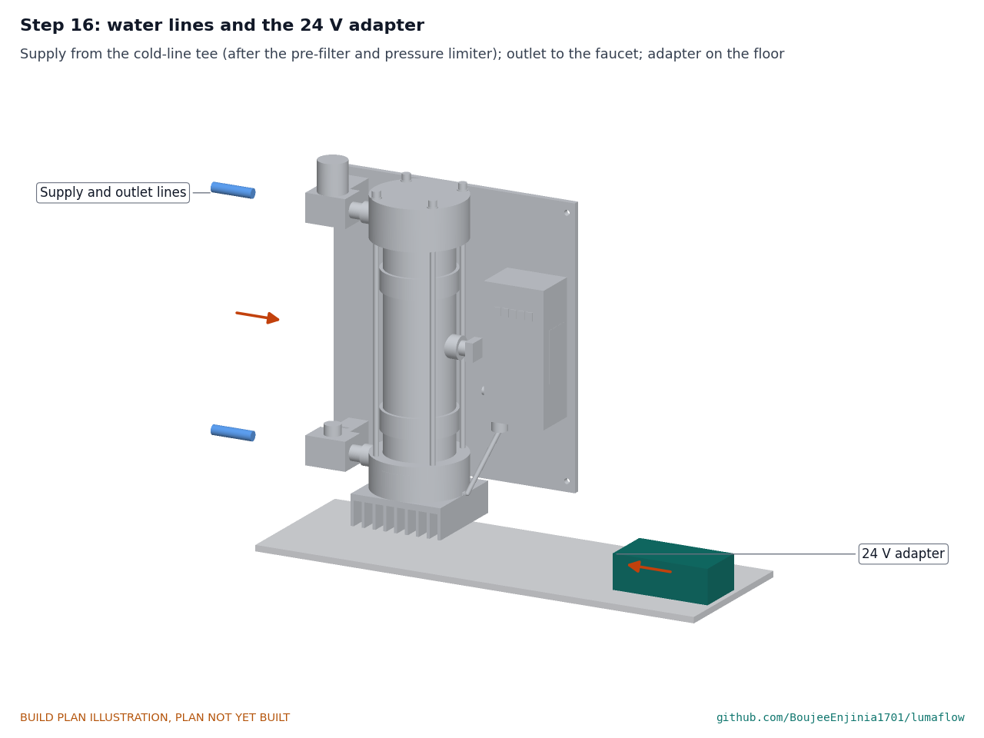
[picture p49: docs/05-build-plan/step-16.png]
Step 16


Supply line from the cold-line tee, after the sediment pre-filter and the pressure-limiting valve set at 4 bar or less, into the flow sensor; outlet line from the valve to the faucet, with the 1.2 L/min restrictor. Adapter on the cabinet floor, plugged into a GFCI or RCD-protected outlet above any likely water level. **Hold point:** safety stops S4 and S5.

## 5. First checks

These are the checks a TRL 4 test report would record; this plan only lists them. Requirement numbers are those of LMF-REQ-001.

*Table 3. First checks.*

| Check | Requirement | How | Pass when |
| --- | --- | --- | --- |
| Pressure and leaks | R7, R17 | Reactor alone, ports plugged except one, filled with water and pressed to 8 bar with a hand pump for 10 minutes, LEDs unpowered | No drop on the gauge and no water at the window, tube ends or sensor boss |
| Flow | R1 | Measure the time to fill a 1 L jug at the faucet | 1.2 L/min, give or take 10 % (about 50 s) |
| Pressure drop | R8 | Gauges before the flow sensor and after the valve, restrictor out of the line | 0.5 bar or less at 1.2 L/min |
| Switch on and run-on | R5 | Open the faucet slowly; watch the UV level bar and time it | LEDs on within 0.5 s of flow above 0.3 L/min; off 5 s after flow stops |
| Valve fails closed | R4 | Unplug the adapter with the faucet open | Flow stops at once |
| Lid interlock | R12 | Lift the lid with water flowing | LED driver input goes dead; valve closes; buzzer sounds |
| LED head interlock | R12 | Eyewear on. With water flowing and the LEDs on, pull the LED head's plug from its socket. Then, with the plug back in, the water off and the adapter unplugged, take out the four head screws and try to slide the head clear of the cap | Removing the plug stops the LEDs at once, the valve closes and the buzzer sounds; the cable stops the head before it is clear of the cap |
| UV level bar | R18 | With clear water flowing, add a little instant coffee to the supply | The bar loses segments as the sensor reading falls, and the last one goes out as the alarm trips |
| No UV-C outside | R12 | UV-C indicator card at every joint, the gland and the sensor boss with the LEDs on | No card shows any change |
| Board temperature | R10 | Thermistor reading after 10 minutes of flow at 25 °C water | 50 °C or less |
| Power | R9 | Plug-in power meter, flowing and idle | 25 W or less flowing; 0.5 W or less on standby |
| Sensor signal | R4 | Amplifier output with clear water flowing | A steady reading that falls when a little instant coffee is added to the supply |
| Service | R15 | Time the removal and refitting of the LED head and of the window | 15 minutes or less each |
| Size | R14 | Tape measure | 350 x 150 x 350 mm or less, adapter excluded |

## 6. Safety stops

Stop at each point. Carry on only when everything listed is true.

- **S1. Before any part goes on the water.** Every wetted part is food-contact grade: 316 stainless, PTFE, fused quartz, EPDM, acetal. No printed plastic touches the water. Parts cleaned with mild detergent and rinsed.
- **S2. Before anything electrical is connected.** The reactor passes the 8 bar leak test of section 5, with nothing electrical within reach of a spray. The window shows no chip or crack under a bright lamp.
- **S3. Before the LEDs are first powered.** The reactor is closed: LED head on and plugged in, both caps and the sensor holder in. The enclosure lid is shut and the lid switch tested open and closed with a meter. Everyone nearby wears UV-C blocking eyewear; no one looks at the window, boss or ports. Water is flowing, so the LEDs are cooled.
- **S4. Before mains is involved.** Only the certified adapter plugs into the mains, into a GFCI or RCD-protected outlet above any likely water level; no mains wiring is part of this build.
- **S5. Before the unit is left running.** The pressure-limiting valve is fitted upstream and set at 4 bar or less; the lid interlock, the valve's fail-closed check and the board temperature check of section 5 all pass. Never bypass the valve or the interlock.
- **S6. Always.** LumaFlow is a research and educational prototype, not a certified water treatment device. Do not drink water from it or rely on it as a barrier; its dose is calculated, not measured.

## 7. Tools, skills and workspace

**Tools.** Hacksaw or bandsaw; bench vice with soft jaws; bench drill; drills 2.5 to 12 mm; countersink; M3, M4 and M8 taps and tap wrench; files and a deburring tool; scriber, square, steel rule and calipers; straight edge and fine abrasive paper on a sheet of glass; 3D printer that prints PETG; soldering iron for heat-set inserts and wiring; ferrule crimper and wire strippers; multimeter; long-reach 3 mm hex key; spanners for the stem adaptors and the holder; torque screwdriver covering about 0.5 to 2 N·m; hand pressure pump with a gauge to 10 bar and blanking plugs; plug-in power meter; UV-C indicator cards. The two end caps, the tube boss and weld, and the photodiode holder go to a machine shop.

**Skills.** No certified trade is needed for the work in this plan. Basic metalwork (marking out, drilling, tapping), 3D printing, push-fit plumbing, through-hole soldering and crimping. TIG welding of the sensor boss and lathe work on the caps are done by the machine shop. All circuits at the unit are 24 V DC or less; mains stays inside the certified adapter.

**Workspace.** A clean bench about 1.2 x 0.6 m; a metalwork corner kept apart from the optical parts so chips and oil stay off the window and liner; a sink or tray for leak tests; a ventilated place for the printer.

**Personal protective equipment.** Safety glasses for cutting and drilling; UV-C blocking eyewear and covered skin whenever the LEDs can run; clean nitrile gloves for the liner and window; no gloves near a turning drill.

## 8. Where the numbers come from

- Model and constructability checks: `cad/src/model.py` (`python cad/src/model.py --check`, 500 checks); STEP and STL exports in `cad/step/` and `cad/stl/`.
- Pictures: `cad/src/build_plan_media.py`, using `.kit/build_views.py`; written to `docs/05-build-plan/` and `cad/drawings/LMF-DWG-101` to `LMF-DWG-111`.
- General arrangement: `cad/drawings/LMF-DWG-001.pdf`, Rev P5.
- Calculations: `docs/04-calcs/01-sizing.md` (LMF-CAL-001 v0.6) and `docs/04-calcs/sizing.py`; window stress [G4], end load [G7], upper cap roof [G8], thermal [F1] to [F3], size and mass [H1, H2], cost [I1], UV level bar [C6]; LED head cable length from the model's interlock check.
- Bill of materials: `bom/bom.csv` and `bom/bom-notes.md`.
- Decisions: `docs/decisions/0003-design-for-construction.md` (LMF-DDR-003), with LMF-DDR-001 and LMF-DDR-002; the register `docs/06-design-decisions.md` (LMF-DEC-001).
- Requirements: `docs/03-requirements.md` (LMF-REQ-001 v0.8).

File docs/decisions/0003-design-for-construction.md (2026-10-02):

---
doc_id: LMF-DDR-003
title: LumaFlow design for construction
project: LumaFlow
doc_type: Design decision record
version: "0.2"
status: Draft
date: '2026-10-02'
author: Amish Chadha
license: CERN-OHL-S-2.0
revisions:
- version: "0.1"
  date: '2026-10-01'
  author: Amish Chadha
  change: Changes that make the concept physically buildable, with the reason for each; made under Amish's 2026-09-30 instruction and open for his review
- version: "0.2"
  date: '2026-10-02'
  author: Amish Chadha
  change: "Accepted by Amish with one exception: the window seat takes a 0.5 mm PTFE washer (A2, option b); A1 decided as (a)"
---

# 0003: Design for construction

- **Date:** 2026-10-01
- **Status:** accepted with one exception. Amish, 2026-10-02: "i approve your recommendations for all 555 open decisions." This covers every change in Tables 1 and 2 and the items in Table 3, decided as recommended on 2026-10-02 and recorded in the design decisions register (LMF-DEC-001). The exception: the window seat of P1 is not metal to glass; a 0.5 mm PTFE washer goes under the window (A2, option b), and the optical check is re-run for the 0.5 mm larger LED gap. A1 is decided as (a), with the LED cable routed so it is too short for the head to come off while still plugged in.

## Context

On 2026-09-30 Amish asked for every repo to get an illustrated prototype build plan, and wrote: "If you are realising that the design cannot be built as per concept - fix the design assumptions to match and be physically feasible as you draw the illustrations." The LumaFlow model of LMF-DDR-002 shows what the reactor does and carries every calculation, but checking it with build123d (overlaps, contacts, removal paths and the process for each part) found eleven places where a part could not be fitted, fixed, sealed or made as drawn (P1 to P11 below).

The changes keep what LumaFlow does: the same 50 mm bore and 242 mm water column, the same six LEDs 0.8 mm under the same 57 x 10 mm window on a 51 mm open span, the same wall sensor position, ports, flow, power and envelope. The optics, dose, dose monitor, pressure drop and window stress results of LMF-CAL-001 are unchanged. Nothing here changes the pitch or the safety case; one item that touches the safety case is left as a proposal (Table 3, A1). Every change is in `cad/src/model.py`, which now runs 324 constructability checks (`python cad/src/model.py --check`): no two parts overlap, the parts of every joint touch, the listed parts keep their clearances, and the window and the LED head each have a clear path out. All 324 pass.

## Decision

*Table 1. Changes made to the model, the BOM and the calculations.*

| # | Problem in the concept | Change made | Why this way |
| --- | --- | --- | --- |
| P1 | The 57 mm window sat in a pocket closed above by the 50 mm bore and below by the 51 mm seat, both narrower than the window, so it could not be put in; it also had no seal. | The pocket is open to the bottom face. The window goes in from below onto a 1 mm EPDM gasket against a new shoulder 13 mm up, and is held by a 316 retaining ring (72 x 51 x 2 mm) with six M3 countersunk screws, flush in a recess in the cap's bottom face. | The way a sight glass is clamped. Water pressure pushes the window onto the ring, so the ring carries the load, as the concept's seat did. The open span (51 mm), the window's height and the 0.8 mm LED gap are unchanged, so the stress [G4] and the optics are unchanged. |
| P2 | The tie rods started at the top of the heat sink base, in 1 mm deep holes, with nothing under them; a nut (8 mm across flats) does not fit the 7.9 mm gap between fins. | Four M5 316 studs threaded 12 mm into the stainless lower cap with threadlocker, through the upper cap, with washers and acorn nuts. Pitch circle 78 to 80 mm, so the studs clear the pipe clamps by 2 mm. | The studs now hold the two caps together against the 2,655 N end load [G7] and nothing else, and the LED head can come off without loosening them. |
| P3 | The LED head (sink, spreader ring, board) had no fixing of its own; the board was loose in the ring with no route out for its cable. | Four M4 socket screws from below, through the fin gaps, the sink base and the ring into the lower cap; three M3 screws hold the board to the sink base; an 8 mm slot in the ring takes the LED cable toward the enclosure. | The head comes off from below with a hex key without opening the water side, which serves R15. |
| P4 | Each tube end butted on a flat cap face with no seal and no location. | The tube is 204 mm long and sits 2 mm into a seat in each cap, on a 1.78 mm EPDM face O-ring in the floor of the seat. In the lower cap the seat leaves a 59 mm spigot that locates the tube and carries the liner. The liner's top 22 mm is turned down to 56 mm so the upper O-ring groove keeps a 1.9 mm wall from the liner pocket. | A face seal pressed by the studs, and a location at each end. The wetted steel length in the lower cap is unchanged, so the thermal path [F2] is unchanged. |
| P5 | The acetal upper cap's roof over the liner pocket was 3 mm thick: about 59 MPa at 8 bar, near the short-term strength of acetal. | Upper cap 30 to 40 mm tall: a 13 mm roof over a 56.2 mm pocket, 2.8 MPa at 8 bar [G8]. | The highest point of the unit is still the valve coil, so the envelope (277 x 100 x 322 mm) is unchanged. |
| P6 | The ports were plain 7 mm holes in 13.5 mm bosses, with no thread for a fitting; the flow sensor and valve were joined to them by 10 mm stubs of tube, too short for push-fit joints. | 20 mm bosses tapped 1/4 BSPP; stainless push-fit stem adaptors screw in, and their stems plug straight into the push-fit ports of the flow sensor and the valve, which keep their positions. | Catalogue parts; no tube stub to cut or kink. |
| P7 | The 316 outlet insert overlapped the PTFE liner by 0.1 mm. | A 316 sleeve 9.5 x 7 x 17 mm pressed into a 9.6 mm bore in the upper cap, ending at the liner's outside face, in line with the liner's 7 mm outlet hole. | Keeps UV-C off the acetal bore, as LMF-DDR-002 E1 requires, without a clash. |
| P8 | The "clamp-on" sensor saddle had no clamp, and the sensor window was a rod through the liner and the tube wall with no seal. | A 316 boss TIG-welded to the tube at mid height, bored 8 mm through; a 10 x 3 mm quartz sensor window on a 0.5 mm EPDM washer in a 10.2 mm seat, pressed by a 316 photodiode holder screwed in on an M12 x 1 thread. | One sealed, welded joint on the pressure wall. The 8 mm open span keeps the window stress at 1.69 MPa [G6]. |
| P9 | The bracket was a printed plate with two closed rings and a solid shelf: the reactor could only be threaded through the rings before its caps went on, the enclosure had no fixing on the shelf, the plate had no wall holes, and the flow sensor and valve had no support. | A 6 mm aluminium plate (242 x 270 mm), drilled and tapped; two bought rubber-lined 65 mm pipe clamps on M8 studs, which open to take the reactor; the enclosure's back screwed straight to the plate with four M4 screws (it moves 27 mm back, same footprint); two printed saddles with a cable tie each steady the flow sensor and the valve; four wall holes. | Every joint is a screw into a tapped hole or an insert, and the reactor can be lifted out after opening two clamps. |
| P10 | The enclosure was one closed box with no lid, although it carries a lid interlock. | A printed body open at the front and a screw-on lid that carries the light pipe and the magnet for the reed switch. | The lid interlock of R12 needs a lid. |
| P11 | The heat sink fins stood on the cabinet floor, at the same level as the adapter. | The unit hangs on its bracket with 25 mm of air under the fins; the adapter stays on the floor. | The thermal calculation [F1] assumes free air round the fins. |

*Table 2. Knock-on changes.*

| Item | Change | Reason |
| --- | --- | --- |
| Cost | BOM lines 1, 2, 4 to 9, 11, 13 to 16 respecified and repriced; line 17 (retaining ring and seals, $12) and line 18 (pipe clamps, $8) added. Value-engineering target: USD 340. Estimated cost of the constructable design: USD 402 (USD 62 over the target) [I1]. The concept was $338.00. | Parts and machining added for construction. Savings worth trying are in the design decisions register (LMF-DEC-001). |
| Calculations | LMF-CAL-001 v0.4: new G8 (upper cap roof); heat capacity 802 to 781 J/K [F1]; acetal-cap comparison 31.4 to 30.5 min [F5]; R16 reported against the target. Dose, monitor, power, pressure drop, window, size and requirement status otherwise unchanged. | Follows the model. |
| Drawings | LMF-DWG-001 Rev P4; concept sheet LMF-DWG-010 Rev P4; making sketches LMF-DWG-101 to 111 added. | Follows the model. |
| Documents | LMF-REQ-001 v0.6 (R15 note, R16 wording), LMF-PRC-001 v0.6 (components 13 to 18, cost), LMF-PRB-001 v0.6 (cost line). No requirement changed status other than R16, which is now reported as over its value-engineering target. | Follows the model and Amish's 2026-10-01 instruction on budgets. |

*Table 3. Items proposed for Amish, decided by Amish on 2026-10-02.*

| # | Question | Options | Recommendation |
| --- | --- | --- | --- |
| A1 | R12 says the LEDs cannot run with the LED head removed, but the concept has no mechanism for this; now that the head comes off on four screws, it matters. This touches the safety case. | (a) a loop wire in the LED head's plug, so the head cannot come off without unplugging it, which opens a loop the controller watches and cuts the LED supply; (b) a microswitch pressed by the sink base; (c) rely on the procedure and the lid interlock alone. | (a): one more wire pair, no moving part. Decided by Amish, 2026-10-02: (a), with the LED cable routed so it is too short for the head to come off while still plugged in. |
| A2 | The window bears on the lapped stainless ring, metal to glass, as on the concept's seat. A thin PTFE washer under it would spread the load but lift the window 0.5 mm, which changes the LED gap and needs the ray trace re-run. | (a) metal to glass on a lapped ring, as modelled; (b) add a 0.5 mm PTFE washer and re-run LMF-CAL-001 section B. | At first (a) for the first prototype. Decided by Amish, 2026-10-02, on the later recommendation: (b), the 0.5 mm PTFE washer with LMF-CAL-001 section B re-run for the larger LED gap; back to metal on glass only if a TRL 4 pressure test on that seat shows no edge chipping. The model, build plan and calculation still show (a) until they are updated. |

## Consequences

- With the record accepted on 2026-10-02, the window seat changes to a 0.5 mm PTFE washer (A2, option b) and the LED head gets a loop wire in its plug (A1). Neither is yet in the model, the build plan or LMF-CAL-001; both are follow-up actions in `docs/REVIEW.md`.
- `design_state: constructable` in `project.yaml`. The build plan LMF-BLD-001 shows every component and step in pictures generated from the model (`cad/src/build_plan_media.py`).
- Requirement status: 13 met, 1 not met (R3, accepted by D1), 1 at risk (R4), 1 not verifiable at TRL 3 (R15), and R16 over its value-engineering target by USD 62 (LMF-CAL-001 v0.4).
- The photoreal renders (`media/render-*.png`), `media/card.png`, `media/social-preview.png` and the appearance model `cad/src/product_model.py` still show the concept: closed bracket rings, a 30 mm upper cap, the clamp-on sensor saddle and the shelf-mounted enclosure. They need updating on Amish's Mac, where Blender is.
- The flow sensor and valve must have push-fit ports at both ends and a flat face for the saddle; the heat sink's fin gap must take an M4 socket head. These are items to confirm when parts are bought (LMF-DEC-001).

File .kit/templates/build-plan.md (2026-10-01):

---
doc_id: PRJ-BLD-001
title: Project prototype build plan
project: Project name
doc_type: Build plan
version: "0.1"
status: Draft
date: YYYY-MM-DD
author: Amish Chadha
license: CERN-OHL-S-2.0
revisions:
  - version: "0.1"
    date: YYYY-MM-DD
    author: Amish Chadha
    change: First build plan; design made constructable
---

# Project prototype build plan

**Plan, not yet built.** How to build the first proof-of-concept prototype, component by component. Building and testing to it is TRL 4 work. Decisions still to be made are kept in the design decisions register (`docs/06-design-decisions.md`), not here.

## 1. What you are building

Every component, pulled apart and numbered in build order

One short paragraph: what the prototype is, how many components, which are made and which are bought, and the main ways they are made.

## 2. What changed to make it buildable

| Component | The concept had | The buildable design has | Why |
| --- | --- | --- | --- |

## 3. Making the components

### 3.1 Component name

Making sketch

**What it is and what it is made from.**

**How to make it.**

1. Mark out ...
2. Cut ...

**How it fits the parts next to it.**

Close-up of the joint

**Check before moving on.**

## 4. Putting it together

### Step 1: ...

Step 1

## 5. First checks

| Check | Requirement | How | Pass when |
| --- | --- | --- | --- |

## 6. Safety stops

## 7. Tools, skills and workspace

## 8. Where the numbers come from

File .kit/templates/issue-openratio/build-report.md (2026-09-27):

---
name: Build report
about: Tell us what happened when you built, printed or tested part of this design
title: "Build report: "
labels: build-report
---

This is a research and educational prototype, not a medical device. It is a TRL 3 concept and is not released for fabrication. If you build any part of it, you do so at your own risk. Reports help everyone.

**What you built** (part, sub-assembly or test)

**Materials, tools and settings**

**What worked**

**What did not work, with photos or measurements if you have them**

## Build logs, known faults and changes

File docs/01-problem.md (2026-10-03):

---
doc_id: LMF-PRB-001
title: LumaFlow problem statement
project: LumaFlow
doc_type: Problem statement
version: "0.8"
status: Draft
date: '2026-10-02'
author: Amish Chadha
license: CERN-OHL-S-2.0
revisions:
- version: "0.1"
  date: '2026-09-24'
  author: Amish Chadha
  change: Initial scaffold
- version: "0.2"
  date: '2026-09-25'
  author: Amish Chadha
  change: Populate to TRL 2 (problem, users, context, constraints, prior work with sources)
- version: "0.3"
  date: '2026-09-25'
  author: Amish Chadha
  change: Record Amish's decisions (LMF-DDR-001) on the first user, dose target and budget; partner stays open
- version: "0.4"
  date: '2026-09-25'
  author: Amish Chadha
  change: Recommendations accepted by Amish (DDR-002); dose gap closed at 1.2 L/min, pressure limiter at installation, budget figure open
- version: "0.5"
  date: '2026-09-26'
  author: Amish Chadha
  change: Budget top-up approved by Amish ($340)
- version: "0.6"
  date: '2026-10-01'
  author: Amish Chadha
  change: Cost of the constructable design reported against the value-engineering target
- version: "0.7"
  date: '2026-10-02'
  author: Amish Chadha
  change: "Partner as decided on 2026-10-02 (LMF-DEC-001)"
- version: "0.8"
  date: '2026-10-02'
  author: Amish Chadha
  change: "Cost of the constructable design with the 2026-10-02 decisions carried in (USD 416); partner approach status"
---

# LumaFlow problem statement

Point-of-use disinfection often depends on mercury UV lamps that break, need a warm-up, run around the clock and are replaced every year, so households with a private well or an unreliable supply either pay for that upkeep or go without. There is no open, inspectable design for a small UV-C LED reactor that switches on only when water flows and tells the user whether the dose was delivered.

## The problem

Ultraviolet light at about 250 to 280 nm inactivates bacteria, viruses and protozoa by damaging their DNA and RNA, without adding chemicals or changing taste. Household UV systems have used low-pressure mercury lamps for decades. Those lamps have four drawbacks at the scale of one kitchen tap:

1. **Mercury and glass.** The lamp contains mercury inside a quartz sleeve. A cracked sleeve or lamp can release mercury into the water line and the home. The Minamata Convention on Mercury is driving mercury-containing lamps out of general use ([Minamata Convention](https://minamataconvention.org/en/news/mercury-containing-lamps-phased-out-minamata-convention-offices-geneva)), and makers of UV-C LED systems market mercury-free operation as the main reason to switch ([AquiSense](https://aquisense.com/mercury-free/)).
2. **Warm-up and continuous running.** A mercury lamp takes time to reach full output, so household units usually run all day and night even though water flows for only a few minutes a day. That wastes energy and heats standing water.
3. **Annual replacement.** Lamp output falls with use, so suppliers advise replacing the lamp about once a year whether or not it has failed ([Fresh Water Systems](https://www.freshwatersystems.com/blogs/blog/how-to-maintain-your-uv-system)).
4. **Silent failure.** Many low-cost units have no UV sensor. The user cannot tell whether the lamp has aged or the sleeve has fouled. NSF/ANSI 55 Class A systems must include a UV sensor and an alarm, but lower-cost Class B and uncertified units need not ([Fresh Water Systems, NSF Class A and B](https://www.freshwatersystems.com/blogs/blog/nsf-class-a-and-class-b); [ANSI blog on NSF/ANSI 55-2024](https://blog.ansi.org/ansi/nsf-ansi-55-2024-ultraviolet-uv-water-treatment/)).

UV-C LEDs remove the mercury, reach full output in microseconds and can switch with the flow. Their weakness is efficiency: current UV-C LEDs turn only about 2 to 5 % of electrical input into UV-C, and many lose 30 to 50 % of their output within 5,000 to 10,000 h ([Tech-LED selection guide](https://tech-led.com/uv-c-leds-for-disinfection-and-sterilization-component-selection-265-280-nm/); [status of 265 nm LEDs, 2023](https://www.researchgate.net/publication/373791832_Status_of_Performance_and_Reliability_of_265_nm_Commercial_UV-C_LEDs_in_2023)). A reactor that runs only while water flows turns that weakness around: a few minutes of on-time a day makes the rated life last for many years.

## Prior work

- **Commercial UV-C LED units.** AquiSense sells compact flow-through UV-C LED reactors for point-of-use integration ([PearlAqua Micro](https://aquisense.com/products/water-treatment/pearl-aqua-micro/)) and a whole-house point-of-entry unit ([PearlAqua Deca launch](https://aquisense.com/pearlaqua-deca-point-of-entry-launch/)). These are closed designs sold to integrators and households at commercial prices.
- **Research reactors.** Flow-through UV-C LED reactors have been studied for their optics, flow pattern and LED placement ([efficiency improvement of a flow-through reactor](https://www.sciencedirect.com/science/article/abs/pii/S2214714420306966); [cylindrical reactor design optimization](https://www.sciencedirect.com/science/article/abs/pii/S2213343724004962); [dual-wavelength point-of-use device](https://doi.org/10.3390/w17202965)). Reviews conclude that LED reactors are practical at small flows and that reactor design, not only LED power, sets the delivered dose ([critical review, 2024](https://www.sciencedirect.com/science/article/pii/S2589914724000616)). UV-C LED dose response depends strongly on water quality ([UVC-LED efficacy and water quality](https://pubmed.ncbi.nlm.nih.gov/39213680/)).
- **Standards and schemes.** NSF/ANSI 55 Class A calls for 40 mJ/cm² at the rated flow and at 70 % UV transmittance or the alarm set point, whichever is lower; Class B calls for 16 mJ/cm² (sources above). The WHO International Scheme to Evaluate Household Water Treatment Technologies rates devices by their log reduction of bacteria, viruses and protozoa ([WHO HWT scheme](https://www.who.int/tools/international-scheme-to-evaluate-household-water-treatment-technologies)). The US EPA UV guidance gives dose tables per pathogen; adenovirus in particular needs far higher doses than bacteria ([EPA UV toolkit](https://www.epa.gov/system/files/documents/2022-05/uv-toolkit-815-B-21-007_0.pdf)).

The gap LumaFlow addresses is an **open, documented, garage-buildable** tap-scale reactor with flow switching and a dose monitor that fails safe, which researchers, makers and small water projects can inspect, reproduce and test.

## Users and context

| User | Need | Context |
| --- | --- | --- |
| Household on a private well or rainwater tank | Safe drinking water at one tap without chemicals, mercury or a yearly lamp | Under the kitchen sink, feeding a dedicated drinking-water faucet |
| Household with an intermittent or suspect municipal supply | A barrier against microbial contamination after pressure drops or boil-water events | Same, downstream of a sediment or carbon filter |
| Small clinic, school or community water point | A low-maintenance disinfection stage for a drinking-water tap | Indoor, mains power available |
| Researcher or maker | An open reference design to test reactor geometries, LEDs and dose sensing | Lab bench, makerspace |

Typical conditions assumed for the concept: water supply pressure of 2 to 6 bar (29 to 87 psi), water temperature 5 to 30 °C, cabinet air up to 35 °C, and a drinking and cooking demand of about 10 to 20 L per household per day drawn in short bursts.

## Constraints

- Garage-buildable prototype, $340 USD or less in parts (budget raised from $200 to $225 by Amish, LMF-DDR-001 D2, then to $340 by the budget top-up Amish approved on 2026-09-26), from off-the-shelf LEDs, sensors and plumbing plus simple machined end caps. The $340 figure is a value-engineering target (Amish, 2026-10-01); the constructable design of LMF-DDR-003, with the decisions of 2026-10-02 carried in, is estimated at $416.00, $76 over it.
- A drinking-water flow of 1.2 L/min (0.32 gpm) is enough for one tap; it fills a 1 L bottle in about 50 s.
- A sediment pre-filter and a pressure-limiting valve at 4 bar (58 psi) or less are part of the installation.
- Fits under a kitchen sink and connects to a standard cold line with push-fit fittings.
- Wetted parts must be food-contact grade; no printed plastic on the water path.
- Only safety extra-low voltage (24 V DC) at the unit; mains stays inside a certified external adapter.
- Research and educational prototype only. LumaFlow is not a certified water treatment device, and the documents must not claim that its water is safe to drink.

## Out of scope

- Removal of chemicals, metals, nitrate, taste or odor. UV does not remove them, and it leaves no residual disinfectant in the pipes after the reactor.
- Whole-house (point-of-entry) flow rates of 20 L/min or more.
- Turbid or iron-rich water without pre-treatment; UV needs clear water to work.
- Certification testing to NSF/ANSI 55 or the WHO scheme (a later step, not part of this portfolio phase).

## Decisions and open questions

- **First user (decided).** A well-water household with a sediment pre-filter. Decided by Amish, 2026-09-25: go with recommendation (LMF-DDR-001 D9). This sets the design water quality at 90 %/cm UVT or better.
- **Dose target (decided).** The Class A dose level of 40 mJ/cm² is the target for clear water (90 %/cm or better), with an alarm and valve closure below it, and the 70 %/cm test condition kept visibly not met. Decided by Amish, 2026-09-25: go with recommendation (LMF-DDR-001 D1). The first TRL 3 calculation found only 14.7 to 19.0 mJ/cm² in clear water; with the route Amish accepted on 2026-09-25 (LMF-DDR-002: 50 mm bore, high-reflectance liner, 1.2 L/min design flow) LMF-CAL-001 v0.2 gives 51.9 to 76.3 mJ/cm².
- **Partner (decided).** A university extension programme for private well owners, which already samples household wells and can measure UV transmittance on real samples; the Texas A&M AgriLife Extension Texas Well Owner Network is the first candidate to approach. Decided by Amish, 2026-10-02 (LMF-DEC-001). No approach has been made yet and nothing is agreed; a draft first message for Amish to send is in the review note (2026-10-02).

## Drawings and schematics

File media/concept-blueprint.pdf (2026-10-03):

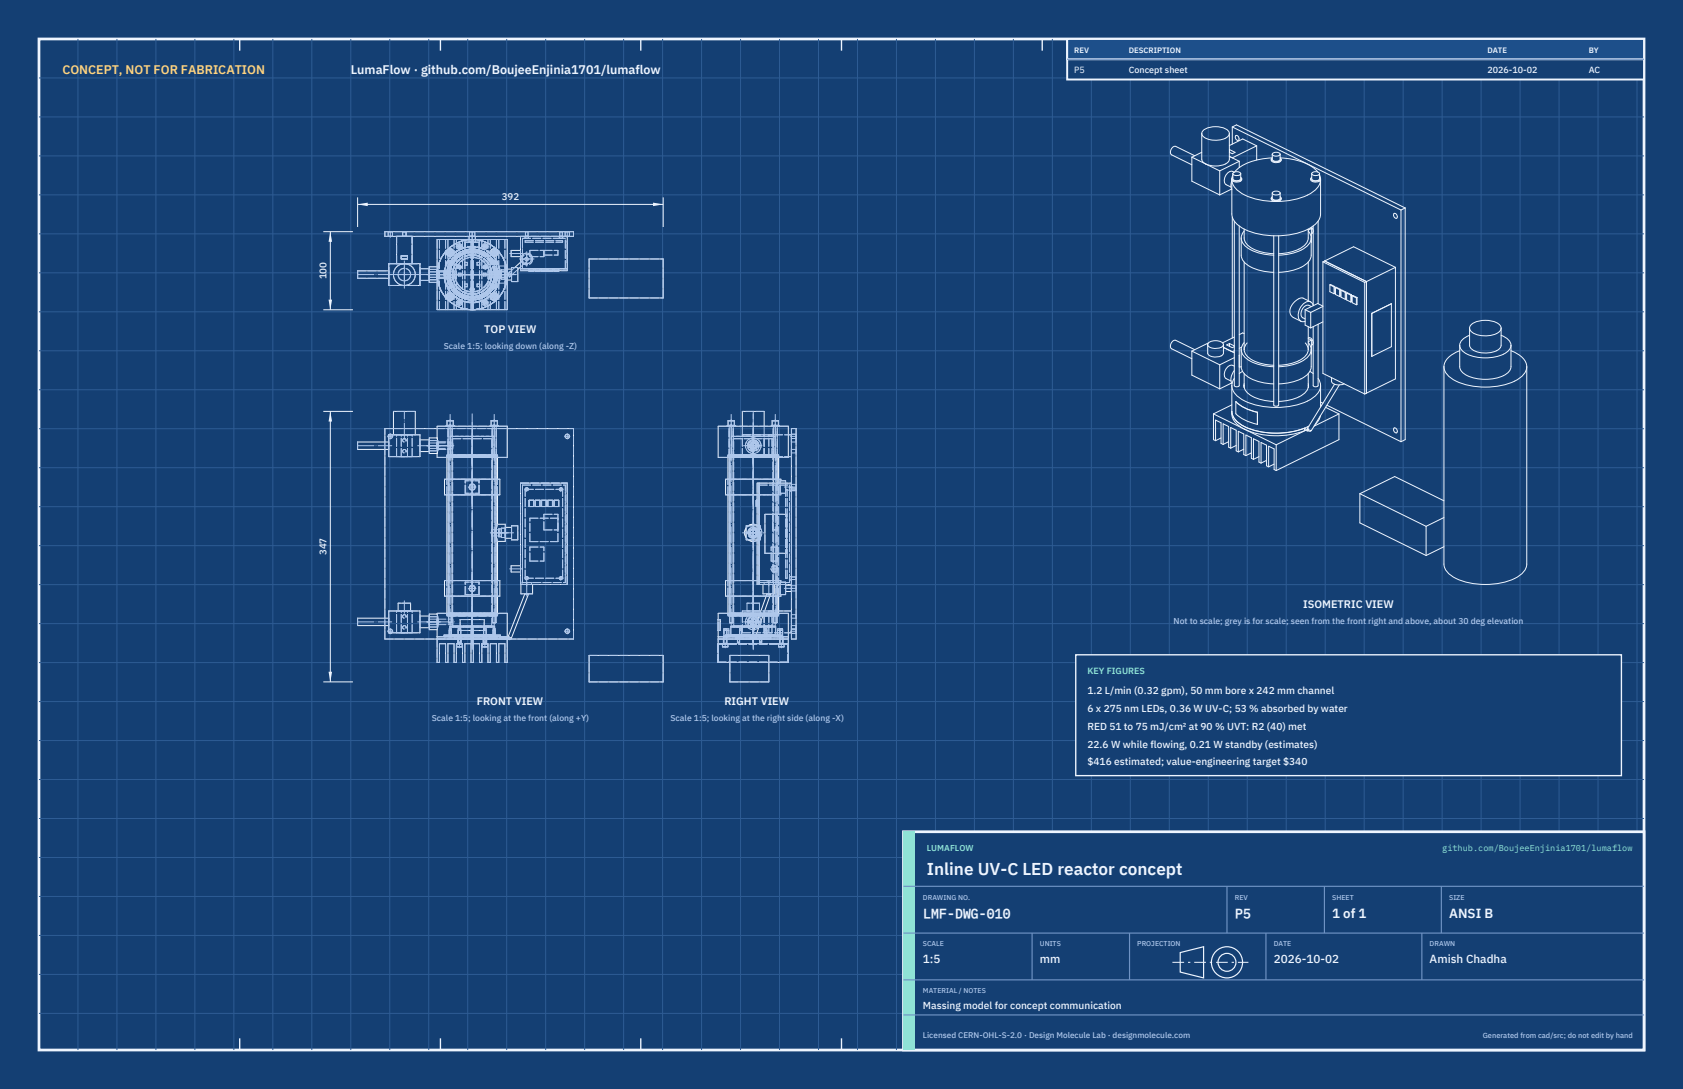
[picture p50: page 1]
CONCEPT, NOT FOR FABRICATION; LumaFlow · github.com/BoujeeEnjinia1701/lumaflow; FRONT VIEW; TOP VIEW; RIGHT VIEW; ISOMETRIC VIEW; REV; DESCRIPTION; DATE; Concept sheet; LUMAFLOW; github.com/BoujeeEnjinia1701/lumaflow; DRAWING NO. LMF-DWG-010; REV P5; SHEET 1 of 1; SIZE ANSI B; SCALE 1:5; UNITS mm; PROJECTION; DRAWN Amish Chadha; Licensed CERN-OHL-S-2.0 · Design Molecule Lab · designmolecule.com; Generated from cad/src; do not edit by hand

Scale 1:5; looking down (along -Z)

Not to scale; grey is for scale; seen from the front right and above, about 30 deg elevation

KEY FIGURES
1.2 L/min (0.32 gpm), 50 mm bore x 242 mm channel
6 x 275 nm LEDs, 0.36 W UV-C; 53 % absorbed by water
RED 51 to 75 mJ/cm² at 90 % UVT: R2 (40) met
22.6 W while flowing, 0.21 W standby (estimates)
$416 estimated; value-engineering target $340

Scale 1:5; looking at the front (along +Y)

Scale 1:5; looking at the right side (along -X)

Inline UV-C LED reactor concept

MATERIAL / NOTES
Massing model for concept communication

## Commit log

2026-09-24 Initial scaffold: standard open hardware layout, CERN-OHL-S v2 + MIT licenses
    Claude-Session: https://claude.ai/code/session_01XuhhSU4W6fYhgCfURbrkut
    [bom.csv]
2026-09-25 Adopt portfolio kit v1.3.0: session commands, scale figure, 3D viewer, flow diagrams
    Adds .claude/commands (/populate, /advance-trl3, /rein-in, /refresh-media)
    so every Claude Code session starts from the standard prompts, and extends
    concept media with a 1.75 m scale figure, an interactive glTF viewer and
    system or energy flow diagrams. TRL cap 3 unchanged.
    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
2026-09-25 Kit v1.3.1: renderer fixes from the TremorTrace pilot
    Context scale parts for small objects, cutaway exclusions, and text
    labels in flow diagrams.
    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
2026-09-25 Populate lumaflow to a strong TRL 2 with concept media (batch 6)
    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
    [bom.csv]
2026-09-25 Advance lumaflow to TRL 3 (batches 5 and 6)
    Decisions approved by Amish 2026-09-25 recorded in DDR-001. TRL 4 is on hold.
    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
    [bom.csv, led-head.step, led-head.stl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]
2026-09-26 Accept all recommendations (DDR-002), switch footer to designmolecule.com, add README write-up with new inspiration point
    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
    [bom.csv, led-head.step, led-head.stl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]
2026-09-27 Product appearance model and photoreal renders
    Adds cad/src/product_model.py (appearance model for renders only, all main
    dimensions from model.py) and Blender renders in media/render-*.png,
    captioned with the project, repository and viewing direction. README leads
    with the product render; trl stays 3.
    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
2026-10-01 Image quality pass: legible exploded views, flow diagrams and drawing sheets
    Kit 1.6.1 image layout: the parts list sits in its own column, number bubbles sit on visible parts and never overlap, small parts get a leader, pictures are cropped to the subject, flow labels keep numbers with their units, and sheet captions and the revision table no longer overprint. Concept images, blueprint and general arrangement sheet regenerated; repo-specific labels moved clear of other text and lines.
2026-10-01 Kit 1.7.0: constructable design, illustrated build plan and design decisions register
    The design is now constructable: every part can be made and fits its neighbours, with each change recorded in a Design for construction decision record (made under Amish's 2026-09-30 instruction; ope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
    FlexHand also credits Dr. Geeti Chadha as a contribut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
    [bom.csv, led-head.step, led-head.stl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]
2026-10-02 Record Amish's approval of the open-decision recommendations
    Amish approved the recommendation on every open decision in the design decisions register ("i approve your recommendations for all 555 open decisions.", 2026-10-02). Each decision is moved to Decisio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
2026-10-03 Carry approved follow-ups into the design and redo photoreal renders
    Amish approved the follow-up actions from the open-decision sign-off ("APPROVED CHANGES, COMPLETE THESE", 2026-10-02), the design-for-construction change tables in ten repos, the last wave's open dec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
    [bom.csv, led-head.step, led-head.stl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]
2026-10-28 Kit 1.9.1 upgrade: pipeline documents and detailed CAD for every option
    Kit 1.9.1 installed (.kit, CLAUDE.md, .claude/commands). Kit 1.8 pipeline: STEM check with fixes under the 2026-10-23 standing instruction, concept options with the current design as option A, URS, PRS, generated RTM, REG, FEA, RSK with design FMEA, MKT, PLN and DDR; kit 1.9 D3 model of every option passing cad/fidelity.json; independent review recorded in the STEM check. Amish's 2026-10-25 decisions recorded where he approved a recommendation; all others proposed, awaiting Amish. Product renders and the options picture follow in a later commit where not yet included.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
2026-10-29 Add Cycles product renders and the concept options picture
    Blender Cycles renders of the kit 1.9.1 model, rendered on Amish's Mac and captioned; media/options.png from the D3 option models (this also clears the failing docs check, which needs the picture); cards and PDFs rebuilt. The options picture labels option A as the current design unless project.yaml records Amish's choice.
2026-10-29 Add the concept options picture rendered from the D3 option models
    media/options.png from Blender Cycles panels of every option, rendered on Amish's Mac; the label reads CURRENT DESIGN unless project.yaml records Amish's choice. Clears the docs check, which needs th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

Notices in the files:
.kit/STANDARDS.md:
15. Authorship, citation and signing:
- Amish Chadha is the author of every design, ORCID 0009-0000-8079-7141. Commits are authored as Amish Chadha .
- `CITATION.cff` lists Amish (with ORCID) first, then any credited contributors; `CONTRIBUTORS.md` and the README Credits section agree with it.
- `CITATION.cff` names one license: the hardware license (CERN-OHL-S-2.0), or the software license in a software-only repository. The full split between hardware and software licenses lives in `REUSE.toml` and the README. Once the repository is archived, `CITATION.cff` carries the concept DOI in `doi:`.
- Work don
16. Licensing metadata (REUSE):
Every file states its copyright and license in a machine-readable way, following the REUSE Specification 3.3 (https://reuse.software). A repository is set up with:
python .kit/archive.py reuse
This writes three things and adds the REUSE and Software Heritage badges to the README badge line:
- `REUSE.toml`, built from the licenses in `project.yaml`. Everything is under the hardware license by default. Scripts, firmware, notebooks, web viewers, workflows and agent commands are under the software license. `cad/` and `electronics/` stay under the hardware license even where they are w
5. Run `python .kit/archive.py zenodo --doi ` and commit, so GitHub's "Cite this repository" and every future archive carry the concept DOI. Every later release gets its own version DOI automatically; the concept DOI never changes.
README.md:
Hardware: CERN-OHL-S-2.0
